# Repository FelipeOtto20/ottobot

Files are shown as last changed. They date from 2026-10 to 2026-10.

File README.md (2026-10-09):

# 🤖 Ottobot

Um robozinho de mesa emocional: dois olhos animados numa telinha OLED, um sensor de toque na cabeça, um sensor de movimento e um buzzer. Ele tem humor, pede carinho, conta piadas, joga, canta e dança, mostra o clima, faz pomodoro com você e conversa pelo app Android com inteligência artificial.

<p align="center">
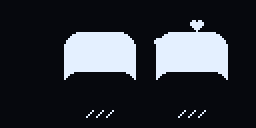
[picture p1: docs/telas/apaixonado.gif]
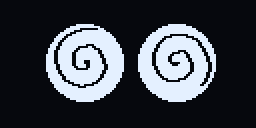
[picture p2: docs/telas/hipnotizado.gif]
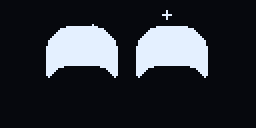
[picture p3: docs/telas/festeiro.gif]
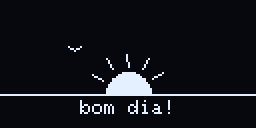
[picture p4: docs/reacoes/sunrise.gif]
   
</p>

> [!IMPORTANT]
> **Os direitos de criação são do projeto original [MONSTRIX - Robot Emotional Companion](https://makerworld.com/pt/models/1941340-monstrix-robot-emotional-companion), de Igor Belyi**, que por sua vez é um remix do [LDR Little Robot](https://makerworld.com/en/models/222658), de Max Kern. Os dois são publicados no MakerWorld sob a licença [CC BY-SA](https://creativecommons.org/licenses/by-sa/4.0/deed.pt_BR). O Ottobot só aperfeiçoa o projeto: firmware novo, sensor de toque, buzzer, página web, app Android e os furos para ímãs na base.

**▶ [Veja todas as telas animadas no simulador online](https://felipeotto20.github.io/ottobot/)**: é a mesma página que o robô serve no Wi-Fi, com o simulador dos olhos.

**⬇ [Baixe a versão mais nova (firmware + app Android)](https://github.com/FelipeOtto20/ottobot/releases/latest)**

**🟦 Também existe uma versão com tela de toque colorida de 480 × 480 e o Diamond Rush original: [veja aqui](#ottobot-com-tela-480-esp32-s3)**

---

## O que ele faz

| | |
|---|---|
| 🎭 **49 telas** | caras e animações que ele sorteia sozinho (você escolhe quais no app) |
| 👄 **Boca** | uma caixinha que se transforma em cada emoção, e o rosto inteiro balança com uma molinha (item da loja) |
| 🥰 **Carinho** | segurar a cabeça dele = carinho; o "coração" esvazia com o tempo e ele fica carente |
| 🪙 **Moedas e loja** | jogos, coração cheio e conquistas dão moedas; a loja do app tem a boca, 20 acessórios e 20 músicas |
| 📋 **Menu** | 3 toques na cabeça: Jogos, Ferramentas e Acessórios |
| 🎮 **15 jogos** | jogados com toques na cabeça, chacoalhando ou inclinando ele |
| 🎩 **32 acessórios** | 12 das conquistas e 20 da loja, e eles combinam com a emoção (orelhas abaixam, auréola vira chifre, chapéu voa) |
| 🙃 **Sente o corpo** | de cabeça pra baixo = silêncio, deitado = dorme, no colo = feliz, inclinado = acha que vai cair |
| 🤝 **Amigos** | dois Ottobots perto um do outro se cumprimentam, conversam e sentem o humor um do outro |
| 🎶 **30 musiquinhas** | 10 de graça e 20 na loja, com coreografia no tempo da música |
| 🧠 **Personalidade** | muda com o jeito que você cuida dele, dia após dia |
| 📖 **Diário** | o que aconteceu em cada dia da semana, com gráfico no app |
| 🌦️ **Clima** | previsão do dia desenhada na tela, avisa quando vai chover, e o tempo muda a cara dele (calor, praia, frio, resfriado, neve) |
| 🍅 **Pomodoro** | 25 min de foco com ele quietinho, depois pausa |
| 💬 **Conversa com IA** | pelo app (Gemini grátis): ele responde e faz animações, caras e músicas |
| 📡 **Sabe quando você chega** | o app escuta o Bluetooth dele; festa quando você entra no quarto |
| ⏰ **Alarmes, cenas do dia, lembretes** | bom dia, meio-dia, boa noite, água, "como foi seu dia?" |
| 🏅 **Conquistas** | 12 medalhas, comemoradas na hora |
| 🎬 **Modo vídeo** | um show de 1 minuto para filmar |

## Telas

Cada tela é só um punhado de números (formato dos olhos, humor, para onde olham, animação que repete, efeito por cima e música). O app e a página do robô têm o catálogo; o robô só toca o que você escolheu.

<table>
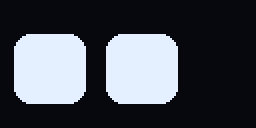
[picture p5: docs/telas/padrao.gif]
Padrão
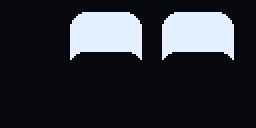
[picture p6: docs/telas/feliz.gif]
Feliz
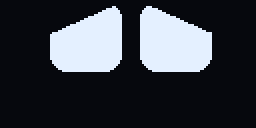
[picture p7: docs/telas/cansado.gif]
Cansado
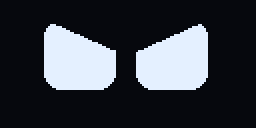
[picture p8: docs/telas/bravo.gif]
Bravo
<tr><td align="center"><br><sub><b>Padrão</b></sub></td><td align="center"><br><sub><b>Feliz</b></sub></td><td align="center"><br><sub><b>Cansado</b></sub></td><td align="center"><br><sub><b>Bravo</b></sub></td></tr>
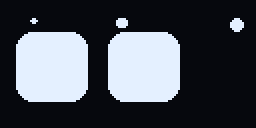
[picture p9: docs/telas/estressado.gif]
Estressado
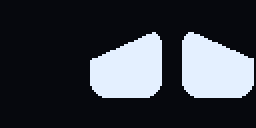
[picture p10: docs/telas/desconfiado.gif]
Desconfiado
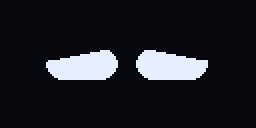
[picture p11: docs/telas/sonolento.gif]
Sonolento
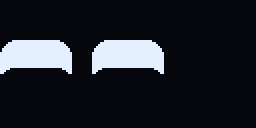
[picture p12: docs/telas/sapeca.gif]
Sapeca
<tr><td align="center"><br><sub><b>Estressado</b></sub></td><td align="center"><br><sub><b>Desconfiado</b></sub></td><td align="center"><br><sub><b>Sonolento</b></sub></td><td align="center"><br><sub><b>Sapeca</b></sub></td></tr>
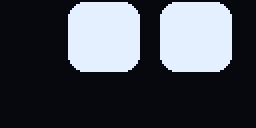
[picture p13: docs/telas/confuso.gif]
Confuso
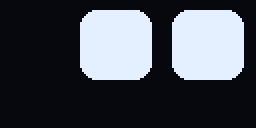
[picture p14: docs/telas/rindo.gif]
Rindo
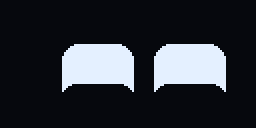
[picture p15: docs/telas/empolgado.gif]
Empolgado
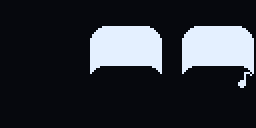
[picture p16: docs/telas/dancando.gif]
Dançando
<tr><td align="center"><br><sub><b>Confuso</b></sub></td><td align="center"><br><sub><b>Rindo</b></sub></td><td align="center"><br><sub><b>Empolgado</b></sub></td><td align="center"><br><sub><b>Dançando</b></sub></td></tr>
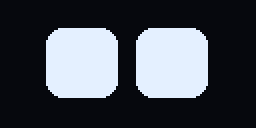
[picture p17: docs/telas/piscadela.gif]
Piscadela
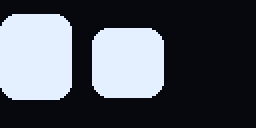
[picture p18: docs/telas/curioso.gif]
Curioso
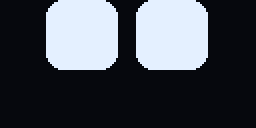
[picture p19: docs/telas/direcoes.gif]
8 direções
<tr><td align="center"><br><sub><b>Piscadela</b></sub></td><td align="center">Pisca-pisca<br><sub><b>Pisca-pisca</b></sub></td><td align="center"><br><sub><b>Curioso</b></sub></td><td align="center"><br><sub><b>8 direções</b></sub></td></tr>
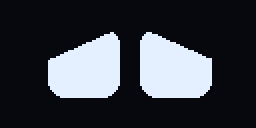
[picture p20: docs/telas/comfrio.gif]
Com frio
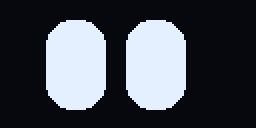
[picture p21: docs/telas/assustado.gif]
Assustado
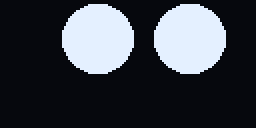
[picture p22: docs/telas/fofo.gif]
Olhos fofos
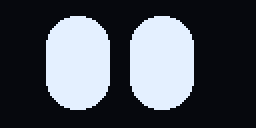
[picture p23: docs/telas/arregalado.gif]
Arregalado
<tr><td align="center"><br><sub><b>Com frio</b></sub></td><td align="center"><br><sub><b>Assustado</b></sub></td><td align="center"><br><sub><b>Olhos fofos</b></sub></td><td align="center"><br><sub><b>Arregalado</b></sub></td></tr>
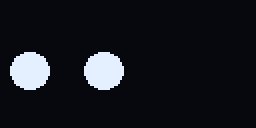
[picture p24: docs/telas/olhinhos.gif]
Olhinhos
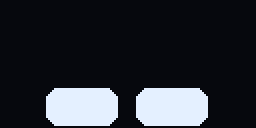
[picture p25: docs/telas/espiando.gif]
Espiando
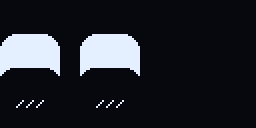
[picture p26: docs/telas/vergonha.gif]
Envergonhado
<tr><td align="center"><br><sub><b>Olhinhos</b></sub></td><td align="center"><br><sub><b>Espiando</b></sub></td><td align="center">Apaixonado<br><sub><b>Apaixonado</b></sub></td><td align="center"><br><sub><b>Envergonhado</b></sub></td></tr>
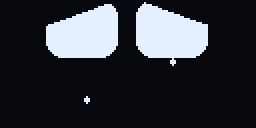
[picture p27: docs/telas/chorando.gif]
Chorando
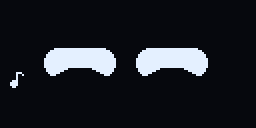
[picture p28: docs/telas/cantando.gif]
Cantando
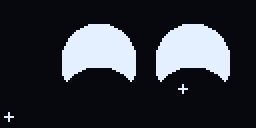
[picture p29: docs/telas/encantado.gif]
Encantado
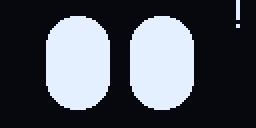
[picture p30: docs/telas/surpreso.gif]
Surpreso
<tr><td align="center"><br><sub><b>Chorando</b></sub></td><td align="center"><br><sub><b>Cantando</b></sub></td><td align="center"><br><sub><b>Encantado</b></sub></td><td align="center"><br><sub><b>Surpreso</b></sub></td></tr>
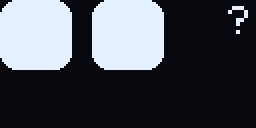
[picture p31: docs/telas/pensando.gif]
Pensando
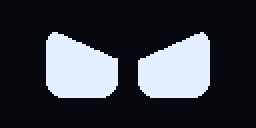
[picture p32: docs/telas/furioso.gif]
Furioso
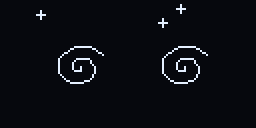
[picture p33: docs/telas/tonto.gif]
Tonto
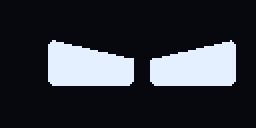
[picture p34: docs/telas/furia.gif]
Fúria
<tr><td align="center"><br><sub><b>Pensando</b></sub></td><td align="center"><br><sub><b>Furioso</b></sub></td><td align="center"><br><sub><b>Tonto</b></sub></td><td align="center"><br><sub><b>Fúria</b></sub></td></tr>
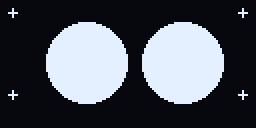
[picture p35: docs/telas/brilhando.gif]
Brilhando
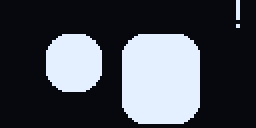
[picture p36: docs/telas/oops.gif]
Oops!
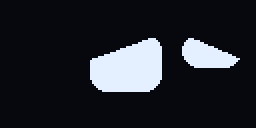
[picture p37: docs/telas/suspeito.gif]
Suspeito
<tr><td align="center"><br><sub><b>Brilhando</b></sub></td><td align="center"><br><sub><b>Oops!</b></sub></td><td align="center"><br><sub><b>Suspeito</b></sub></td><td align="center">Hipnotizado<br><sub><b>Hipnotizado</b></sub></td></tr>
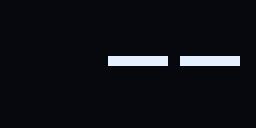
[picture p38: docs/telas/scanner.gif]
Scanner
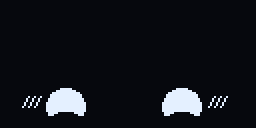
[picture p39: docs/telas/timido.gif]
Tímido
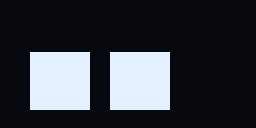
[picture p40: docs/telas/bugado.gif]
Bugado
<tr><td align="center"><br><sub><b>Scanner</b></sub></td><td align="center">Festeiro<br><sub><b>Festeiro</b></sub></td><td align="center"><br><sub><b>Tímido</b></sub></td><td align="center"><br><sub><b>Bugado</b></sub></td></tr>
<tr><td align="center">Ninja<br><sub><b>Ninja</b></sub></td><td align="center">Em pânico<br><sub><b>Em pânico</b></sub></td><td align="center">Zen<br><sub><b>Zen</b></sub></td><td align="center">Cifrão<br><sub><b>Cifrão</b></sub></td></tr>
<tr><td align="center">Olhos de estrela<br><sub><b>Olhos de estrela</b></sub></td><td align="center">Ideia!<br><sub><b>Ideia!</b></sub></td><td align="center">Nocaute<br><sub><b>Nocaute</b></sub></td><td align="center">Emburrado<br><sub><b>Emburrado</b></sub></td></tr>
<tr><td align="center">Língua de fora<br><sub><b>Língua de fora</b></sub></td></tr>
</table>

## Reações e cenas do dia

<table>
<tr><td align="center">Abertura (ao ligar)<br><sub><b>Abertura (ao ligar)</b></sub></td><td align="center">Carinho (segurar)<br><sub><b>Carinho (segurar)</b></sub></td><td align="center">Chacoalhar: tonto, depois bravo<br><sub><b>Chacoalhar: tonto, depois bravo</b></sub></td></tr>
<tr><td align="center">Sono e canção de ninar<br><sub><b>Sono e canção de ninar</b></sub></td><td align="center">Wi-Fi conectou<br><sub><b>Wi-Fi conectou</b></sub></td><td align="center">Relógio<br><sub><b>Relógio</b></sub></td></tr>
<tr><td align="center">Bom dia<br><sub><b>Bom dia</b></sub></td><td align="center">Meio-dia<br><sub><b>Meio-dia</b></sub></td><td align="center">Boa noite<br><sub><b>Boa noite</b></sub></td></tr>
</table>

- **Toques rápidos**: cada quantidade (1 a 8 toques) faz o que você escolher no app. Padrão: 1 = alegria, 2 = dança, 3 = menu, 5 = hora, 6 = QR code da página.
- **Segurar**: carinho. Quanto mais tempo, mais derretido: "^ ^", olhos de coração, nas nuvens (com brilhos e notinhas).
- **Chacoalhar** (balançar pros lados várias vezes; um tranco ou deitar não conta): fica tonto (olhos em espiral) e depois bravo e suando. Duas vezes seguidas: **nocaute** (olhos em X, estrelinhas girando e o chapéu voa).
- **Sono**: dorme depois de um tempo parado, só à noite ou nunca. Dormindo, um toque canta canção de ninar e 3 toques rápidos acordam.

## Boca, clima no rosto e acessórios

Gravados direto da tela do robô.

<table>
<tr><td align="center" width="33%">👄 Boca<br><b>👄 Boca</b><br><sub>canta, fala, sorri, fica triste, bravo, faz "o" e mostra a língua; o rosto balança com uma molinha</sub></td><td align="center" width="33%">🌡️ Clima no rosto<br><b>🌡️ Clima no rosto</b><br><sub>calor, praia, frio, resfriado (atchim!) e neve: só quando o tempo pede</sub></td><td align="center" width="33%">🎩 Acessórios que sentem<br><b>🎩 Acessórios que sentem</b><br><sub>a nuvem vira sol ou chove forte, orelhas abaixam, auréola vira chifre, o chapéu voa no nocaute</sub></td></tr>
</table>

- **Boca** (comprada na loja, liga e desliga no app): uma caixinha que muda de tamanho e escorrega de uma forma para outra, com pontinhas que sobem no sorriso e descem na tristeza. Ela segue tudo: o humor dos olhos, cada nota que toca, as falas, o sono, o susto e o carinho.
- **Clima no rosto**: as caras de clima não entram no rodízio de telas. O tempo traz elas: quente = calor e às vezes praia (com óculos escuros), frio = congelando e às vezes resfriado, nevando = neve (com gorro e cachecol). A IA do app comenta.
- **Emoções novas**: cifrão (quando ganha moedas), olhos de estrela, ideia (a lâmpada acende quando ele chama para brincar), nocaute, emburrado ("hmpf") e língua de fora.

## Moedas e loja

- **Ganhar**: jogos (até 20 moedas por partida e +10 ao bater um recorde, até 150 por dia), coração cheio com carinho (+30, uma vez por dia) e cada conquista (+50). Ele faz olhos de cifrão quando ganha.
- **Loja** (aba Loja do app): a boca (800), 20 acessórios de 250 a 1200 (tapa-olho de pirata, bruxa, viking, astronauta, nuvem de chuva, sobrancelhas que mudam com o humor, bigode, herói...) e 20 músicas clássicas de 150 a 350. Dá para provar no robô antes de comprar, e tudo fica salvo nele.
- **Caça-níquel** aposta 10 moedas de verdade: 7 7 7 paga 350 (raro!), trios de 30 a 120, dois 7 = 50, outro par = 12, um 7 sozinho devolve a aposta.

## Menu, acessórios e gestos

<table>
<tr><td align="center" width="33%">📋 Menu<br><b>📋 Menu</b><br><sub>3 toques abrem; toque desce, segure até apitar e solte para escolher</sub></td><td align="center" width="33%">🎩 Acessórios<br><b>🎩 Acessórios</b><br><sub>experimente no rosto dele; os trancados mostram a medalha que libera</sub></td><td align="center" width="33%">📡 Atualizando<br><b>📡 Atualizando</b><br><sub>a tela durante uma atualização pelo Wi-Fi</sub></td></tr>
</table>

- **Menu** (3 toques, dá para trocar no app; abre na hora do último toque): **Jogos** (com o seu recorde embaixo de cada um), **Ferramentas** (relógio, cronômetro, pomodoro, clima, dado, humor e QR do app), **Acessórios** (os das conquistas e os comprados) e **Sair**. Quando um jogo acaba ele volta para o rostinho.
- **De cabeça pra baixo** (1,5 s): liga ou desliga o silêncio.
- **Deitado de lado** (3 s): boceja e dorme; em pé de novo, acorda.
- **No colo** depois de um tempo parado: olha pra você feliz, com coraçõezinhos.
- **Inclinado pro lado**: acha que vai cair. Olhos arregalados e tremendo escorregam para o lado mais baixo, ele grita e as letras do grito caem com a gravidade. Reto de novo: "ufa!".
- **Amigos**: dois Ottobots no mesmo Wi-Fi (ou os dois sem Wi-Fi de casa) se falam por ESP-NOW. Eles se cumprimentam ("oi, robô do Fulano!"), de vez em quando um pergunta e o outro responde, e um sente o humor do outro: carinho vira coraçõezinhos, chacoalhão vira "tudo bem?", sono vira bocejo.

## Mais animações

Também gravadas direto da tela do robô.

<table>
<tr><td align="center" width="33%">✨ Abertura<br><b>✨ Abertura</b><br><sub>com a contagem 3-2-1 do modo vídeo</sub></td><td align="center" width="33%">🤡 Piada<br><b>🤡 Piada</b><br><sub>pergunta, suspense, susto ou espanto e gargalhada</sub></td><td align="center" width="33%">🎉 Festa de chegada<br><b>🎉 Festa de chegada</b><br><sub>quando você entra no quarto</sub></td></tr>
<tr><td align="center" width="33%">🌦️ Clima<br><b>🌦️ Clima</b><br><sub>previsão do dia e o comentário dele</sub></td><td align="center" width="33%">🎶 Música com coreografia<br><b>🎶 Música com coreografia</b><br><sub>dança no tempo de cada batida</sub></td><td align="center" width="33%">🎧 Modo música<br><b>🎧 Modo música</b><br><sub>dança e mostra as frequências da música do celular</sub></td></tr>
<tr><td align="center" width="33%">🍅 Pomodoro<br><b>🍅 Pomodoro</b><br><sub>foco de 25 min com ele concentrado</sub></td><td align="center" width="33%">🙂 Como foi seu dia?<br><b>🙂 Como foi seu dia?</b><br><sub>responde com 1, 2 ou 3 toques</sub></td><td align="center" width="33%">💧 Lembrete de água<br><b>💧 Lembrete de água</b><br><sub>um toque = bebi</sub></td></tr>
<tr><td align="center" width="33%">📅 Contagem regressiva<br><b>📅 Contagem regressiva</b><br><sub>dias que faltam para uma data</sub></td><td align="center" width="33%">🔳 QR code<br><b>🔳 QR code</b><br><sub>abre a página dele no celular</sub></td><td align="center" width="33%">🕒 Relógio<br><b>🕒 Relógio</b><br><sub>hora grande e data</sub></td></tr>
<tr><td align="center" width="33%">🥰 Carinho<br><b>🥰 Carinho</b><br><sub>coraçõezinhos e bochechas coradas</sub></td><td align="center" width="33%">😵 Tonto e bravo<br><b>😵 Tonto e bravo</b><br><sub>depois de um chacoalhão</sub></td></tr>
</table>

## Carinho, humor e personalidade

- O **coração** vai de 0 a 100%: carinho e toques enchem, o tempo e chacoalhões esvaziam. Abaixo de 30% ele fica **carente**: coração vazio, pede carinho e **não obedece** ninguém até ganhar um carinho longo. Abaixo de 10% ele chora. O "modo carente" pode ser desligado.
- **Personalidade**: todo dia o dia anterior empurra um pouco. Muito carinho deixa ele **carinhoso** (o coração esvazia mais devagar e ele diz que gosta de você); muitos jogos e toques, **brincalhão** (chama para jogar); esquecido fica **carente**; dias quietos, **calmo**.
- **Diário**: carinhos, tempo de carinho, toques, jogos, piadas, pomodoros, copos de água, humor do dia e coração médio, 7 dias.
- **Piadas**: ele encena (pergunta, suspense, susto ou espanto, risada). Ele guarda 20; a IA do app troca as já contadas por novas, com trocadilhos que funcionam em português, e uma segunda IA faz de crítica e só deixa passar as boas. 3 vezes por dia ele conta uma quando você está no quarto.

## Mini jogos

Gravados direto da tela do robô.

<table>
<tr><td align="center" width="33%">⚡ Reflexo<br><b>⚡ Reflexo</b><br><sub>3, 2, 1… toque quando aparecer o !</sub></td><td align="center" width="33%">🎶 Genius<br><b>🎶 Genius</b><br><sub>Repita: toque = curto, segure = longo</sub></td><td align="center" width="33%">🔢 Adivinha<br><b>🔢 Adivinha</b><br><sub>Ele pensou de 1 a 10: responda com toques</sub></td></tr>
<tr><td align="center" width="33%">✊ Jokenpô<br><b>✊ Jokenpô</b><br><sub>1 toque pedra, 2 papel, 3 tesoura</sub></td><td align="center" width="33%">🦖 Dino<br><b>🦖 Dino</b><br><sub>Pule cactos e aves baixas; ave alta: fique no chão</sub></td><td align="center" width="33%">🌙 Pouso<br><b>🌙 Pouso</b><br><sub>Segure para ligar o motor e pouse devagar</sub></td></tr>
<tr><td align="center" width="33%">🎯 Alvo<br><b>🎯 Alvo</b><br><sub>Toque quando a barra estiver no meio</sub></td><td align="center" width="33%">⏱️ Cronômetro<br><b>⏱️ Cronômetro</b><br><sub>Conte o tempo de cabeça e toque quando passar</sub></td><td align="center" width="33%">🐍 Snake<br><b>🐍 Snake</b><br><sub>Toque = vira à direita, segure = à esquerda</sub></td></tr>
<tr><td align="center" width="33%">🎲 Dado<br><b>🎲 Dado</b><br><sub>Chacoalhe ou toque para jogar o dado</sub></td><td align="center" width="33%">🎰 Caça-níquel<br><b>🎰 Caça-níquel</b><br><sub>Aposta 10 moedas: 7 7 7 = 350, trios 30 a 120, par 12</sub></td><td align="center" width="33%">🪜 Cobras e escadas<br><b>🪜 Cobras e escadas</b><br><sub>1 toque: contra ele · 2 toques: duas pessoas · depois toque = dado</sub></td></tr>
<tr><td align="center" width="33%">🐦 Flappy<br><b>🐦 Flappy</b><br><sub>Toque para bater as asas e passe entre os canos</sub></td><td align="center" width="33%">🧱 Torre<br><b>🧱 Torre</b><br><sub>Toque para soltar o bloco bem em cima da torre</sub></td><td align="center" width="33%"><b>🌀 Labirinto</b><br><sub>Incline o robô para rolar a bolinha até o buraco, contra o tempo; cada fase é um labirinto maior</sub></td></tr>
</table>

**💎 Diamantes** se joga com o controle do celular: 50 missões de quebra-cabeça em 8 mundos (pedras que caem, chaves e portas, botões e grades, aranhas, martelo, gancho e passagens secretas). O mundo novo, **Castelo** (missões 41 a 50), tem fases feitas à mão que juntam tudo isso. Todas as missões são conferidas por um programa que as resolve sozinho.

Durante um jogo nada mais funciona (comandos, cenas, chacoalhar). **Segure a cabeça 3 s para sair** (aparece a dica e uma barrinha; no Pouso segurar é o motor, então ele sai quando a nave bate). Perdeu: **GAME OVER** e volta para o rostinho; nenhum jogo recomeça sozinho. 10 s sem jogar, ele sai. Os recordes ficam salvos e as partidas dão moedas.

## Musiquinhas e dança

| | Música | Duração |
|---|---|---|
| 🤖 | Ottobot vibes | 0:20 |
| 🎹 | Para Elisa | 0:12 |
| 🎂 | Parabéns pra você | 0:18 |
| ⭐ | Brilha, brilha | 0:27 |
| 🎻 | Ode à alegria | 0:33 |
| 🦾 | Marcha do robô | 0:36 |
| ✨ | Chuva de estrelas | 0:43 |
| ⛰️ | Rei da montanha | 0:46 |
| 🌙 | Soninho | 0:48 |
| 🎉 | Festa 8-bit | 0:51 |

Mais 42 na loja do app: 40 de domínio público (Bate o sino, Noite feliz, Cancan, Marcha turca, Danúbio azul, Lago dos cisnes, Guilherme Tell, The Entertainer, Canon em Ré, Frère Jacques, La cucaracha, Os santos, Greensleeves, Marcha nupcial, Oh! Susana, Ninar de Brahms, Pequena serenata, Minueto em Sol, Rema rema, Primavera, Korobeiniki do Tetris, Maria tinha um carneirinho, O velho MacDonald, Ponte de Londres, Yankee Doodle, Amazing Grace, Auld Lang Syne, Corrida de Camptown, Clementine, A dona aranha, Feliz Natal, Deck the halls, Quinta sinfonia, Tocata e fuga, Marcha fúnebre, Novo Mundo, Pop! Lá vai o furão, Alouette, Bingo e As rodas do ônibus) e trechos dos temas de **Missão Impossível** e **Sweden** (Minecraft). As músicas a partir da 33ª pedem o firmware 52 ou mais novo.

A coreografia é calculada no app para o tempo exato de cada batida e o robô dança no mesmo relógio da música: pulinhos no tempo forte, olhos seguindo a melodia (nota aguda olha para cima), giros, piscadas, olhos crescendo, efeitos que trocam a cada 2 compassos e olhos de coração no fim. Também tem **modo música**: o celular escuta a música que está tocando (pelo microfone) e ele dança mostrando as frequências. Volume do bipe ajustável no app.

## Companhia no dia a dia

- 🌦️ **Clima** (só no Wi-Fi de casa): [Open-Meteo](https://open-meteo.com/), sem chave. Cidade escolhida no app ou descoberta pela internet. Mostra de manhã, quando vai chover e umas 2 vezes por dia. Em dia quente ele fica com calor (e às vezes sonha com a praia), no frio treme (e às vezes pega um resfriado), e com neve olha os flocos caindo.
- 🍅 **Pomodoro**: 25 min de foco (ele fica quieto e concentrado; um toque dá um incentivo), 5 min de pausa (15 a cada 4 rodadas) e depois chama você de volta.
- 🙂 **"Como foi seu dia?"** à noite, respondido com 1, 2 ou 3 toques. 💧 **Lembrete de água** durante o dia, um toque = bebi.
- 📅 **Contagem regressiva** para datas marcadas no app (prova, viagem, aniversário), com festa no dia.
- ⏰ **Alarmes** com dias da semana e soneca. 🌅 **Cenas do dia** em horários escolhidos. 🔇 **Silêncio** total ou em horários. 🌙 **Tela fraquinha à noite**.
- Tudo que é para ler (perguntas, lembretes, medalhas, datas, clima) **espera você estar perto**: celular no quarto (Bluetooth) ou logo depois de um toque.

### Conquistas

Cada medalha libera um acessório (menu → Acessórios) e dá 50 moedas.

🐻 **Abraço de urso**: um carinho longo, até ele ficar nas nuvens (uns 18 s segurando) → libera: orelhas de urso  
❤️ **Coração cheio**: encher o carinho dele até 100% → libera: laço  
📅 **Semana de carinho**: carinho nele 7 dias seguidos → libera: coroa  
🍅 **Foco de aço**: completar 10 pomodoros → libera: óculos  
📚 **Dia produtivo**: 4 pomodoros no mesmo dia → libera: faixa  
💧 **Hidratado**: 8 copos de água num dia (toque nele quando ele lembrar) → libera: boné  
🤡 **Plateia fiel**: ouvir 30 piadas dele → libera: nariz de palhaço  
🦖 **Dino veloz**: 500 pontos no Dino → libera: óculos escuros  
🎶 **Memória boa**: chegar na rodada 8 do Genius → libera: chapéu de mago  
⚡ **Rápido como raio**: reflexo abaixo de 250 ms → libera: fones  
📖 **Diário em dia**: contar como foi seu dia 5 vezes → libera: cartola  
🌟 **Dia completo**: no mesmo dia: carinho, jogo, pomodoro e água → libera: auréola

## App Android

- **Início**: o rosto dele ao vivo, coração, atalhos, foco, musiquinhas, modo vídeo, jogos, diário, personalidade, conquistas, datas, cenas, caras e recado na telinha.
- **Conversa**: IA grátis ([chave do Gemini](https://aistudio.google.com/apikey), fica só no celular). Ele responde em frases curtas, escolhe animações, inventa caras e músicas e reage quando você faz carinho nele.
- **Loja**: moedas, a boca, acessórios e músicas para provar e comprar, e escolher o que ele usa.
- **Perto**: radar do Bluetooth, festa quando você chega, aviso quando ele está carente, 3 piadas por dia.
- **Controle**: setas ou joystick, A e B, tela em pé ou deitada. Em **✏️ Ajustar** você arrasta cada botão para onde quiser, muda o tamanho e liga o modo canhoto; fica salvo no celular, um jeito para a tela em pé e outro para deitada.
- **Ajustes**: tudo do robô (telas, toques, horários, sono, som, Wi-Fi, senha, lembretes, clima) e as atualizações, com as etapas e a porcentagem na tela.

Instale pelo arquivo `ottobot.apk` da [última versão](https://github.com/FelipeOtto20/ottobot/releases/latest) ou pela página do robô (`http://ottobot.local`). Android 12 ou mais novo. Quando sai uma versão nova aqui, o app avisa e atualiza o robô e ele mesmo.

## Ottobot com tela 480 (ESP32-S3)

Uma segunda versão do Ottobot, numa placa pronta com tela colorida de toque. É o mesmo Ottobot do OLED (emoções, reações, cenas, acessórios, moedas, loja, app e IA), com o rosto na tela grande e tudo comandado pelo toque. Não precisa montar nada: a placa já vem com tela, toque, Wi-Fi e amplificador de som.

**A tela**

| | |
|---|---|
| Placa | **GUITION ESP32-4848S040** (vendida como "ESP32-S3 4848S040", painel de parede de 4") |
| Processador | ESP32-S3 de dois núcleos a 240 MHz, 16 MB de flash, 8 MB de PSRAM |
| Tela | 4", IPS, 480 × 480, controlador ST7701 num barramento RGB de 16 bits (RGB565) |
| Toque | capacitivo GT911 (I2C SDA 19 / SCL 45) |
| Som | amplificador NS4168 (I2S) com conector para alto-falante de 4 a 8 Ω |
| Outros | Wi-Fi, Bluetooth LE, USB-C (CH340) e microSD; algumas versões trazem 1 a 3 relés, que o Ottobot não usa |

**Como funciona**

- Use a placa com o **cabo USB do lado direito**: o rosto, os jogos e o toque já estão girados para essa posição.
- O rosto é o mesmo do OLED, ampliado no meio da tela com bordas suavizadas e degradê azul. Tocar na tela é como tocar na cabeça dele: carinho, toques contados e jogos.
- Dormindo, ele só acorda com **6 toques rápidos**, e acorda tonto (a placa não tem o chacoalhão do sensor de movimento).
- O botão **≡** no canto de cima abre o menu tocável. **Anterior** e **Próximo** só aparecem quando existe outra página.
- A rede própria se chama **Ottobot-480** (senha inicial `ottobot1`) e a página é `http://ottobot-480.local` (só Wi-Fi e download do app; os comandos ficam no app).
- O app reconhece a placa sozinho e cuida de dois robôs (um OLED e um 480): **Ajustes › Cadastrar outro robô** e o botão **Robôs** na tela inicial. Os dois robôs se encontram pelo Wi-Fi, se cumprimentam e conversam quando estão na mesma rede.

**Alto-falante**

A placa sai de fábrica com o amplificador desligado do ESP32. Para ter som, mova os três resistores de 0 Ω de **R25, R26 e R27** para **R21, R22 e R23** e ligue um alto-falante pequeno (4 a 8 Ω) no conector da placa. Esses resistores não têm lado. Com isso os pinos IO1 (BCLK), IO2 (LRCLK) e IO40 (DIN) vão para o amplificador em vez dos relés. Sem a troca, tudo funciona, só que mudo. O volume é o mesmo do app.

**Diferenças e exceções**

| | OLED (ESP32-C3) | Tela 480 (ESP32-S3) |
|---|---|---|
| Toque | sensor na cabeça | a tela inteira, com botões |
| Sensor de movimento (MPU6050) | vem montado | opcional (I2C SDA 19 / SCL 45) |
| Sem o sensor de movimento | — | Batatinha frita sai do menu e do app; Labirinto, Snake, Corrida, Pouso e Diamantes mostram setas na tela |
| Acordar | chacoalhar ou 3 toques | 6 toques rápidos (acorda tonto) |
| Som | buzzer | alto-falante pelo amplificador da placa (veja acima) |
| Jogos de toques contados | conta os toques | botões na tela: Jokenpô (Pedra, Papel, Tesoura), Adivinha (1 a 10), Genius (Curto, Longo) |
| Mini jogos | telinha 128 × 64 | tela inteira, coloridos e animados (Flappy com céu e canos, Dino de dia e de noite, Snake, Torre, Corrida, Caça-níquel, Jokenpô, Genius, Adivinha, Reflexo, Alvo, Tempo, Pouso na lua, Labirinto, Diamantes, Dado, Cronômetro e Cobras e escadas com escadas de madeira e cobras com olhos) |
| Rosto e animações | pixels da tela OLED | os mesmos, com bordas suavizadas e degradê azul, sem piscar |
| Menu | toque desce, segurar escolhe | itens tocáveis |
| Brilho | — | 100% de dia, 70% à noite |
| Jogo exclusivo | — | Diamond Rush original (abaixo) |
| Atualizações | pelo app (estas versões do GitHub) | pelo cabo USB; o app nunca oferece o firmware do OLED para ela |

**Firmwares diferentes**

O OLED tem um firmware só (Arduino, ESP32-C3), que o app atualiza pelo Wi-Fi com as versões publicadas aqui.

A tela 480 guarda **dois firmwares na mesma flash** e liga sempre pelo Ottobot:

| Parte da flash | Endereço | O que tem |
|---|---|---|
| nvs | 0x9000 | configurações, moedas e recordes do Ottobot; os dois firmwares usam (o jogo deixa ali as moedas das fases) |
| app0 | 0x10000 (3 MB) | **Ottobot**: o mesmo código do OLED, com a tela 480 (Arduino_GFX), o toque e o som por I2S |
| app1 | 0x310000 (3 MB) | **Diamond Rush**: máquina virtual Java ([Flint JVM](https://github.com/FlintVN/FlintESPJVM), ESP-IDF 5.5) com a tela, o toque, o controle do app e um sintetizador MIDI para o som |
| ffat | 0x610000 (9,9 MB) | arquivos do jogo (classes Java, imagens e os textos em português) e os saves |

Ao escolher **Jogos › Diamond Rush**, o Ottobot marca o firmware do jogo para a próxima partida e reinicia. O jogo, assim que abre, já marca o Ottobot de volta: **SAIR**, a opção de sair do jogo ou qualquer reinício voltam ao Ottobot. Enquanto o jogo está aberto, o app não muda configurações (elas são do Ottobot) e avisa isso.

Os dois firmwares são gravados pelo cabo USB. O Diamond Rush é da Gameloft e não é distribuído aqui.

**Exclusivo da tela 480: Diamond Rush**

O clássico de celular da Gameloft (2006) rodando o jogo Java original dentro da própria placa, com a camada de jogos de celular do [ESP32-J2ME](https://github.com/bbnmn4800/ESP32-J2ME). O celular não é preciso: os 3 mundos (40 fases) e o progresso ficam na placa.

- **Em português**: menus, avisos, loja e dicas traduzidos, e as instruções falam dos botões da tela ("Toque A para jogar", "Estrela: reinicia e perde uma vida").
- **Com som**: as músicas e os efeitos do jogo (arquivos MIDI) tocam no alto-falante por um sintetizador feito para a placa.
- Abre pelo menu **Jogos › Diamond Rush** ou pela lista de jogos do app (só aparece para a tela 480).
- Controle na tela: setas, **A** (ação), **B** (menu), **★** (voltar ao checkpoint); os cantos de baixo da imagem são o **Skip/OK** e o **voltar** do jogo. O controle do app também funciona, com a ★.
- O botão **≡** no canto abre **CONTROLES** (mostra ou esconde o controle) e **SAIR** (volta ao Ottobot).
- Cada fase vencida pela primeira vez dá moedas para o Ottobot, fora do limite diário dos jogos: **Angkor** 50 a 350, **Baviera** 150 a 630, **Tibete** 300 a 1080 (17.330 no jogo todo). O valor aparece no canto de cima da tela na hora, e as moedas entram quando você volta para ele, com os olhos de cifrão.

## Hardware e montagem

**🔧 [Manual de montagem completo](MONTAGEM.md)**: peças, passo a passo das ligações com desenhos, como prender na caixa e problemas comuns.

**🖨️ [Modelo 3D (OttoBot.3mf)](modelo-3d/README.md)**: a caixa do MONSTRIX com furos para ímãs de 4 × 2 mm na base.

<p align="center">Mapa de pinos</p>

| Peça | Pino do ESP32-C3 |
|---|---|
| Tela OLED 0,96" SSD1306 (I2C 0x3C) | SDA → GPIO8, SCL → GPIO9 |
| MPU6050 (I2C 0x68) | SDA → GPIO8, SCL → GPIO9 (mesmos da tela) |
| Sensor de toque TTP223 | I/O → GPIO10 (colado com cola quente por dentro da cabeça) |
| Buzzer passivo | + → GPIO20 |
| Todos | VCC → 3V3, GND → GND |

A tela fica presa com mini parafusos.

Bibliotecas: Adafruit SSD1306 e GFX, [FluxGarage RoboEyes](https://github.com/FluxGarage/RoboEyes) 1.1.1, MPU6050_light. Placa: ESP32 core 3.3, partição "Minimal SPIFFS (com OTA)".

## Conectar

1. Conecte o celular no Wi-Fi **Ottobot** (senha padrão `ottobot1`; troque no app) e a página abre sozinha, ou abra `http://192.168.4.1`.
2. Pela página ou pelo app, coloque o robô no Wi-Fi de casa: aí é só abrir `http://ottobot.local` sem sair da sua internet.

Para quem quiser mexer, o robô tem uma API HTTP simples: `/api/state`, `/api/config`, `/api/do`, `/api/show`, `/api/say`, `/api/song`, `/api/diary`, `/api/jokes`, `/api/buy`, `/api/update`.

## Créditos e direitos

- **Projeto original e direitos de criação**: [MONSTRIX - Robot Emotional Companion](https://makerworld.com/pt/models/1941340-monstrix-robot-emotional-companion), de **Igor Belyi**, remix do [LDR Little Robot](https://makerworld.com/en/models/222658), de **Max Kern** (MakerWorld, CC BY-SA). O Ottobot é um aperfeiçoamento desse projeto.
- Olhos animados pela biblioteca [RoboEyes](https://github.com/FluxGarage/RoboEyes), da FluxGarage.
- Tela 480: [Arduino_GFX](https://github.com/moononournation/Arduino_GFX); Diamond Rush pela [Flint JVM](https://github.com/FlintVN/FlintESPJVM) e pelo [ESP32-J2ME](https://github.com/bbnmn4800/ESP32-J2ME) (MIT). Diamond Rush © Gameloft.
- Clima do [Open-Meteo](https://open-meteo.com/); localização aproximada do ip-api.com.

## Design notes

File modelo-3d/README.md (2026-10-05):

# 🖨️ Modelo 3D do Ottobot

> [!IMPORTANT]
> **Os direitos de criação são do projeto original [MONSTRIX - Robot Emotional Companion](https://makerworld.com/pt/models/1941340-monstrix-robot-emotional-companion), de Igor Belyi**, que por sua vez é um remix do [LDR Little Robot](https://makerworld.com/en/models/222658), de Max Kern. Os dois são publicados no MakerWorld sob a licença [CC BY-SA](https://creativecommons.org/licenses/by-sa/4.0/deed.pt_BR). O Ottobot só aperfeiçoa o projeto: firmware novo, sensor de toque, buzzer, página web, app Android e os furos para ímãs na base.

Arquivo: **[OttoBot.3mf](OttoBot.3mf)**. Abre no Bambu Studio ou no OrcaSlicer, já separado em placas.

| Placa 1 · tampas das orelhas | Placa 2 · cabeça e orelhas | Placa 3 · base com furos para ímãs |
|:-:|:-:|:-:|
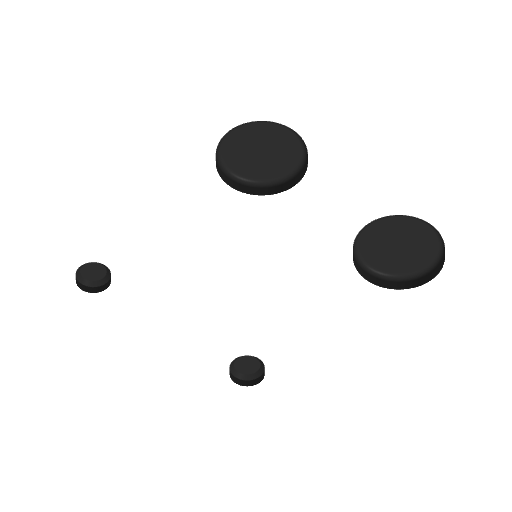
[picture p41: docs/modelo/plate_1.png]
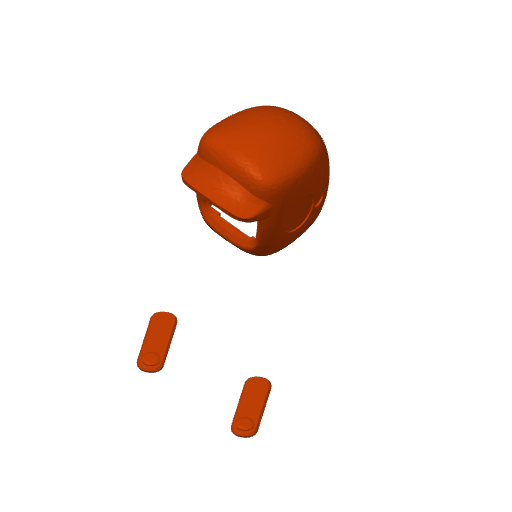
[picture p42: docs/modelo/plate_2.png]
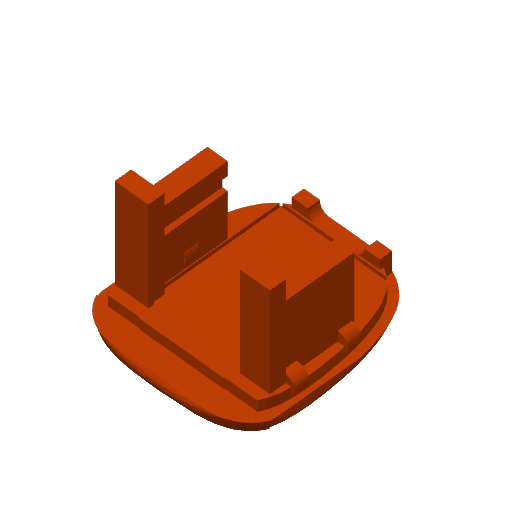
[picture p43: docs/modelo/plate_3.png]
|  |  |  |

## O que mudou em relação ao MONSTRIX

- **Base com 2 furos para ímãs de neodímio de 4 × 2 mm** (4 mm de diâmetro, 2 mm de altura).

## Impressão

- PLA. O arquivo já vem com o perfil de impressão (Bambu Lab A1 mini); em outras impressoras é só trocar a impressora no fatiador.
- Duas cores, como no original: corpo laranja e tampas das orelhas pretas.
- Os ímãs entram depois de impresso, com uma gota de cola.

## Licença

Este modelo é derivado de obras sob [CC BY-SA 4.0](https://creativecommons.org/licenses/by-sa/4.0/deed.pt_BR) e segue a mesma licença: pode usar, imprimir e modificar, **dando crédito** aos autores (Max Kern → Igor Belyi → Ottobot) e **compartilhando suas versões com a mesma licença**.

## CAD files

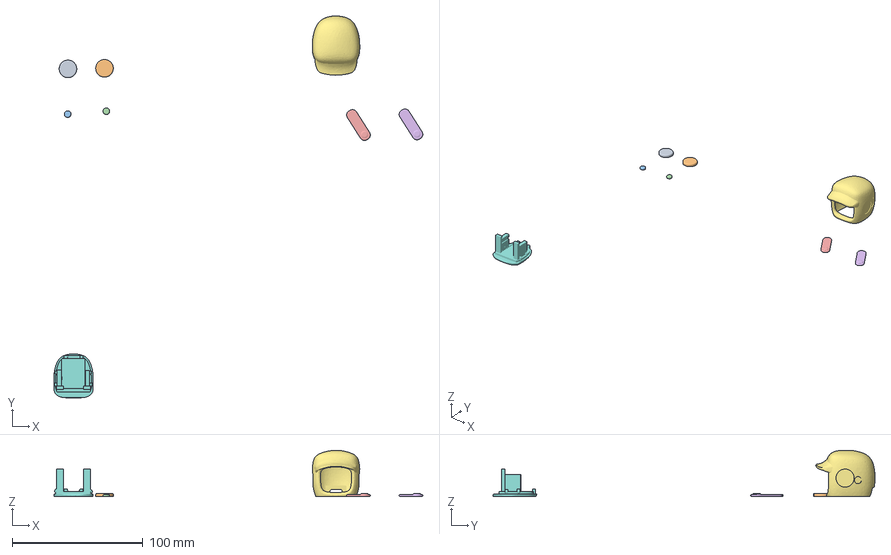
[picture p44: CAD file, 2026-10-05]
modelo-3d/OttoBot.3mf
282.6 x 292.7 x 35.6 mm
LittleBotOLEDearAV1.stl x 2
LittleBotOLEDearCV1.stl x 2
LittleBotOLEDearBV1.stl x 2
Frantic Wluff (20).stl
Frantic Wluff (23).stl

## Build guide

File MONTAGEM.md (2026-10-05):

# 🔧 Manual de montagem do Ottobot

> [!IMPORTANT]
> **Os direitos de criação são do projeto original [MONSTRIX - Robot Emotional Companion](https://makerworld.com/pt/models/1941340-monstrix-robot-emotional-companion), de Igor Belyi**, que por sua vez é um remix do [LDR Little Robot](https://makerworld.com/en/models/222658), de Max Kern. Os dois são publicados no MakerWorld sob a licença [CC BY-SA](https://creativecommons.org/licenses/by-sa/4.0/deed.pt_BR). O Ottobot só aperfeiçoa o projeto: firmware novo, sensor de toque, buzzer, página web, app Android e os furos para ímãs na base.

Montagem simples: 5 peças eletrônicas ligadas por fios a um ESP32-C3, dentro da caixa impressa em 3D. Não precisa de placa nem de resistores: tudo funciona em **3,3 V**, direto nos pinos do ESP32-C3.

## 1. Peças

| | Peça | Qtd | Para quê |
|---|---|:-:|---|
| 🧠 | **ESP32-C3** (4 MB de flash, USB) | 1 | o cérebro: Wi-Fi, Bluetooth e o programa |
| 👀 | **Tela OLED 0,96"** SSD1306 128×64, I2C (4 pinos) | 1 | os olhos |
| 🫨 | **MPU6050** (acelerômetro e giroscópio, I2C) | 1 | sentir quando o chacoalham |
| 👆 | **Sensor de toque TTP223** (capacitivo) | 1 | a "cabeça": toques e carinho |
| 🔊 | **Buzzer passivo** | 1 | sons e músicas |
| 🧲 | **Ímãs de neodímio 4 × 2 mm** | 2 | na base (opcional) |
| 🖨️ | **Caixa impressa em 3D** | 1 | [modelo-3d/OttoBot.3mf](modelo-3d/README.md) |
| 🔩 | Mini parafusos | — | prender a tela pelos furos do módulo |
| 🔥 | Cola quente | — | prender o sensor de toque |
| 🔌 | Fios finos e cabo USB | — | ligações e energia |

> [!NOTE]
> O buzzer precisa ser **passivo** (sem oscilador interno). O buzzer ativo só faz um apito fixo e não toca as músicas. Dica: o passivo normalmente não tem o adesivo por cima e, ligado direto na pilha, só faz um "clique".

## 2. Mapa de pinos

<p align="center">Mapa de pinos do ESP32-C3</p>

| Pino do ESP32-C3 | Vai para | Fio sugerido |
|---|---|---|
| **3V3** | Tela VCC · MPU6050 VCC · Toque VCC | 🔴 vermelho |
| **GND** | Tela GND · MPU6050 GND · Toque GND · Buzzer − | ⚫ preto |
| **GPIO8** (SDA) | Tela SDA · MPU6050 SDA | 🔵 azul |
| **GPIO9** (SCL) | Tela SCL · MPU6050 SCL | 🟡 amarelo |
| **GPIO10** | Toque I/O | 🟢 verde |
| **GPIO20** | Buzzer + | 🟣 roxo |

## 3. Passo a passo das ligações

Faça uma peça de cada vez e confira antes de passar para a próxima.

### Passo 1 · Tela OLED

<p align="center">Ligação da tela OLED</p>

- 4 fios: **VCC → 3V3**, **GND → GND**, **SDA → GPIO8**, **SCL → GPIO9**.
- A ordem dos pinos varia entre módulos (alguns começam por VCC, outros por GND): **siga o nome impresso na plaquinha**, não a posição.

### Passo 2 · MPU6050

<p align="center">Ligação do MPU6050</p>

- Mesmos 4 sinais da tela. **SDA e SCL vão nos mesmos pinos** que a tela usa (GPIO8 e GPIO9): torça ou solde os dois fios juntos no mesmo pino. É assim que funciona o I2C: as duas peças conversam pelo mesmo par de fios, cada uma com seu endereço (tela 0x3C, MPU6050 0x68).
- Os outros pinos do MPU6050 (XDA, XCL, AD0, INT) ficam sem ligar.

### Passo 3 · Sensor de toque TTP223

<p align="center">Ligação do sensor de toque</p>

- **VCC → 3V3**, **GND → GND**, **I/O → GPIO10**.
- Ele é capacitivo: sente o dedo **através do plástico** da caixa, não precisa ficar exposto.

### Passo 4 · Buzzer passivo

<p align="center">Ligação do buzzer</p>

- **+ → GPIO20**, **− → GND**. Se o seu buzzer não tiver marcação, tanto faz o lado.
- O volume é ajustado pelo app (Ajustes › Som); não precisa de resistor.

> [!TIP]
> Fios curtos deixam a tela e o MPU6050 estáveis: no I2C, até uns 15 a 20 cm. Se a tela piscar ou travar, encurte os fios de SDA e SCL.

## 4. Montagem na caixa

<p align="center">Como as peças ficam presas na caixa</p>

1. **Imprima a caixa**: [modelo-3d/OttoBot.3mf](modelo-3d/README.md) (Bambu Studio ou OrcaSlicer).
2. **Tela**: presa na frente com **mini parafusos** nos furos do módulo. Aperte só até firmar: o vidro da tela trinca fácil.
3. **Sensor de toque**: colado com **cola quente**, por dentro, no topo da cabeça. O lado com o círculo (a área de toque) fica encostado no plástico, sem folga e sem bolha de cola no meio, que atrapalha a leitura.
4. **MPU6050**: prenda firme (cola quente ou fita dupla face), para ele sacudir junto com a caixa.
5. **Buzzer**: perto de uma abertura, para o som sair melhor.
6. **Ímãs** (opcional): dois ímãs de **4 × 2 mm** nos furos da base, com uma gota de cola.

> [!IMPORTANT]
> Ao ligar, **não encoste na cabeça e deixe o robô parado** por 2 segundos. Nesse momento o sensor de toque e o MPU6050 se calibram. Se você estiver tocando ou mexendo nele, o toque fica falhando ou ele acha que está sendo chacoalhado.

A imagem da tela já sai girada 180° no firmware (`setRotation(2)`), como no projeto original. A borda da caixa cobre as últimas linhas de baixo da tela; por isso os textos ficam um pouco mais para cima.

## 5. Primeiro teste

| Faça | Ele deve |
|---|---|
| Ligar no USB | mostrar a abertura OTTOBOT (letras caindo) e abrir os olhos |
| Um toque na cabeça | pular de alegria com uma musiquinha |
| Segurar a cabeça | derreter em "^ ^" com coraçõezinhos |
| Chacoalhar | ficar tonto (olhos em espiral) e depois bravo |
| Conectar no Wi-Fi **Ottobot** | abrir a página dele no celular |

## 6. Problemas comuns

| Problema | O que fazer |
|---|---|
| Tela não acende | confira 3V3 e GND; veja se SDA e SCL não estão trocados |
| Tela pisca ou trava | fios de SDA/SCL mais curtos; solda bem feita |
| Toque dispara sozinho ou não responde | religue sem encostar nele (recalibra); veja se não ficou cola entre o sensor e o plástico |
| Chacoalhar não faz nada | MPU6050 solto: prenda firme; religue com ele parado |
| Sem som | buzzer ativo no lugar do passivo; volume e "Silenciar tudo" no app (Ajustes › Som) |
| Tela apagada à noite | "Tela fraquinha à noite" com brilho muito baixo: aumente em Ajustes › Lembretes e noite |

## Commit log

2026-10-05 docs: README com tudo que o Ottobot faz, GIFs das telas e simulador online
2026-10-05 docs: manual de montagem, modelo 3D com furos para imas e creditos do projeto original
    [OttoBot.3mf]
2026-10-05 docs: diagramas de montagem mais limpos
2026-10-05 docs: GIFs um pouco menores para caber 3 por linha
2026-10-06 README: menu, roupas, gestos, notificacoes e amigos (fw 37 / app 4.0)
    Novas secoes e GIFs (menu, roupas, notificacao, tela de atualizacao), Labirinto
    nos jogos, medalhas com a roupa que liberam, pagina do simulador atualizada.
2026-10-09 README: Ottobot com tela 480 (ESP32-S3), diferencas, excecoes e Diamond Rush (app 5.13)
